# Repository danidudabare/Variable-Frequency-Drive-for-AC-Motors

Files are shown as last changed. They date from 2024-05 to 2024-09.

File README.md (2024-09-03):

# Variable Frequency Drive (VFD) for AC Motors

## Introduction
This project involves the design and development of a Variable Frequency Drive (VFD) for controlling the speed and torque of AC motors. The VFD adjusts the motor's input frequency and voltage, enabling precise control over motor performance in various industrial and commercial applications. This project is part of the EN2160 - Electronic Design Realization module at the University of Moratuwa.
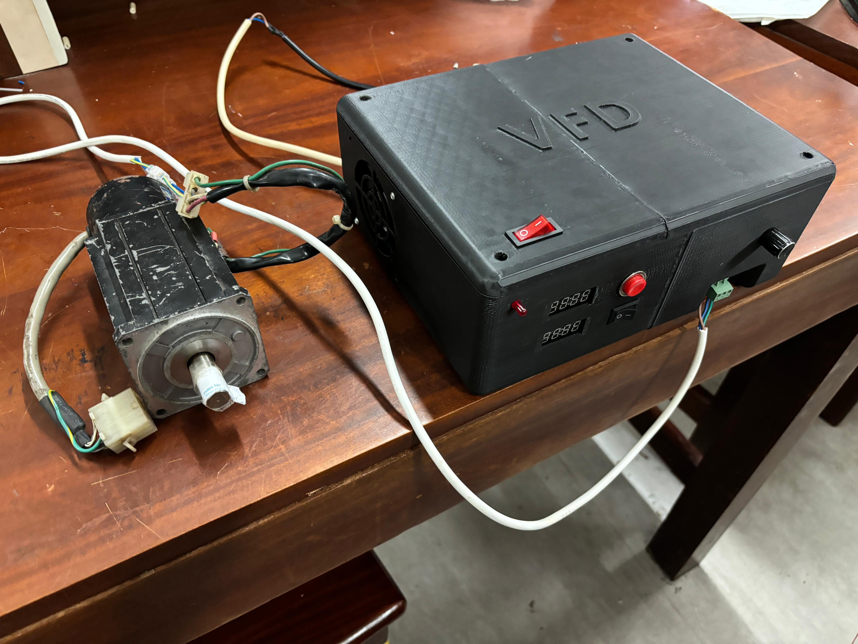
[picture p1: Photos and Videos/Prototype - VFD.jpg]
Prototype VFD


## Electronic Design
### Power Circuit
The Power Circuit is responsible for converting the high-voltage AC input to a stable DC output, which powers the motor and other components. Key elements include a full-wave rectifier, smoothing capacitors, and AC-DC converters. The design also incorporates a bypass relay circuit to manage inrush currents.

### Intelligent Power Module (IPM)
The IPM is the heart of the VFD, combining high-speed switching IGBTs with integrated protection features like overcurrent and thermal shutdown. It interfaces with the microcontroller unit (MCU) to receive control signals and provide system feedback.

### Microcontroller Unit (MCU)
The MCU controls the VFD operation by generating PWM signals that modulate the output frequency and voltage to the motor. It also manages system diagnostics, user input, and communication with the IPM. The MCU used in this project is the ATmega328-PU.

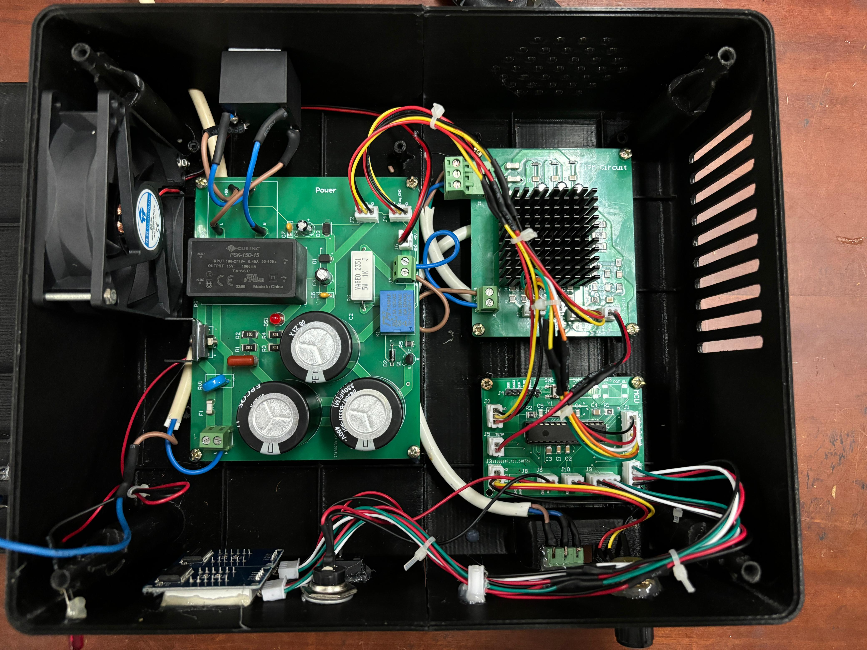
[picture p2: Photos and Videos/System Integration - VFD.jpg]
System Integration - VFD


## Enclosure Design
The enclosure for the VFD is designed to house all the electronic components securely, providing protection against environmental factors and physical damage. The enclosure is made of ABS material, designed with both top and bottom parts that are molded to fit the internal circuits. Detailed design drawings and 3D-printed prototypes were developed to ensure proper fit and functionality.

## Source Code
The source code for this project is written in C++ and is responsible for controlling the MCU. The code handles PWM generation, user inputs via potentiometers and switches, and displays motor parameters on digital LED displays. The code is optimized for real-time motor control, ensuring accurate and responsive operation of the VFD.

## Testing and Prototyping
Extensive testing and prototyping were conducted to ensure the reliability and performance of the VFD. This included PCB testing for power circuits, IPM, and MCU integration, as well as real-time testing with an AC motor to verify speed and torque control. The final prototype demonstrated successful operation under various load conditions, confirming the design's effectiveness.
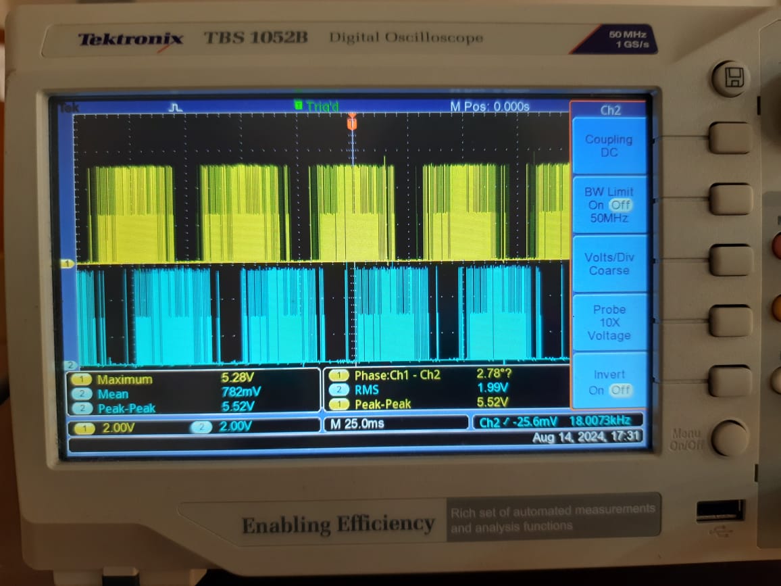
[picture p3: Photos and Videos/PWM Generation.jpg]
PWM Generation

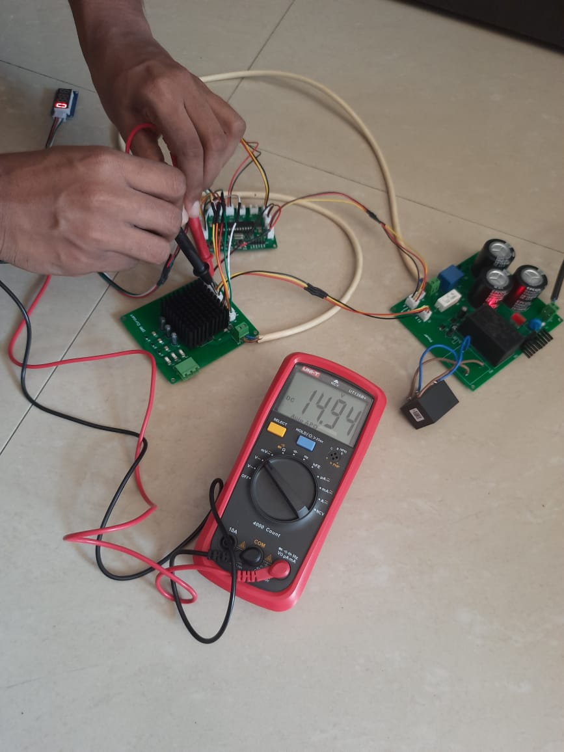
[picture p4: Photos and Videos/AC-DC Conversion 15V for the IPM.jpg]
AC-DC Conversion 15V for the IPM


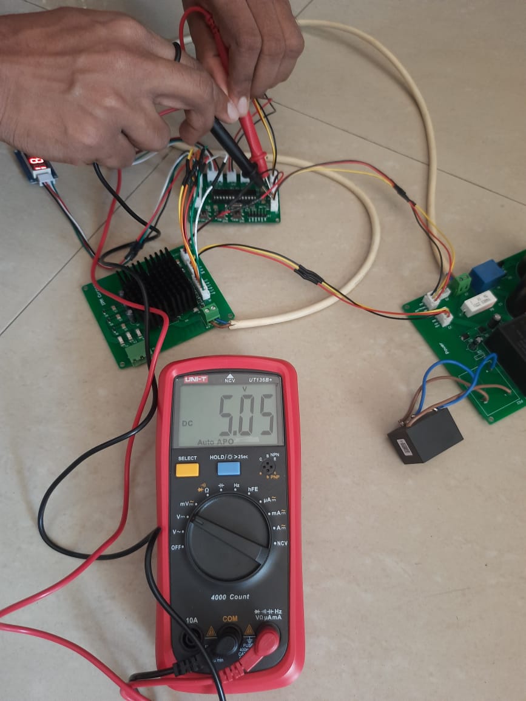
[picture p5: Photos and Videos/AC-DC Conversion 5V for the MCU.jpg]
AC-DC Conversion 5V for the MCU


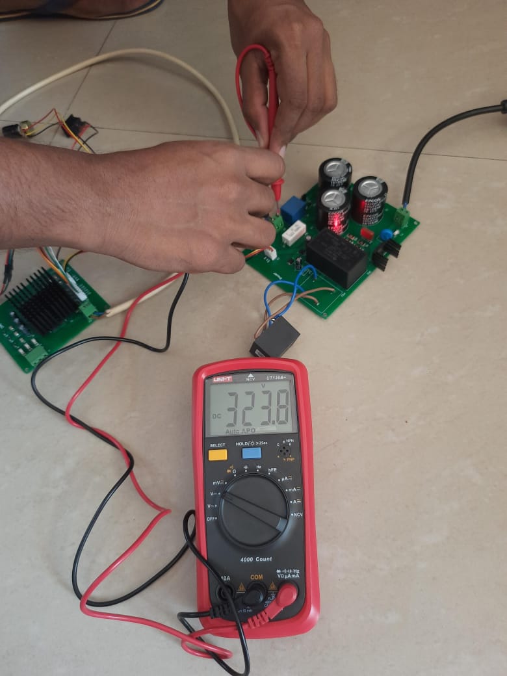
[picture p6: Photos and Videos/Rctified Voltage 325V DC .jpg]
Rectified Voltage 325V DC


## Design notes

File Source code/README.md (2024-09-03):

This project is designed for the ATmega328P (8-bit) microcontroller and is built without relying on Arduino libraries. It uses the AVR GCC 8-bit compiler and the standard C++ libraries. The modified TM1637Display library included in this repository is essential for the display functionality.

# Microcontroller
ATmega328P (8-bit)

# Modifications
Converted from Arduino to AVR: The code has been fully adapted to work with AVR libraries, removing dependencies on Arduino libraries.
Removed Unnecessary Functions: Functions related to single-phase AC motors have been removed as the project focuses solely on 3-phase AC motor control.
Added Reverse_3_Phase() Function: This new function allows reversing the rotation direction of the 3-phase AC motor.
Converted Display Libraries: The display functionality has been converted from Arduino-specific libraries to AVR-compatible libraries.

# Instructions for Compilation
To compile this code using the AVR GCC 8-bit compiler, follow these steps:

# 1. Include the Modified Display Library
Ensure you have included the modified TM1637Display library provided in this repository. This library is crucial for the correct operation of the displays used in this project.

# 2. Setting Up the Environment
Verify that the AVR GCC 8-bit compiler is correctly installed on your system.

# 3. Compiling the Code
Use your preferred IDE or command-line tools compatible with AVR GCC to compile the code. Ensure the modified TM1637Display library is included in the compilation process.

# Important Notes
Arduino-Free: This project does not use Arduino libraries and relies solely on AVR libraries and standard C++ libraries.
Port Requirements: The display functionality is designed to work exclusively with Port B pins. The code will not function correctly if other ports are used.

# License
This project is licensed under the MIT License.

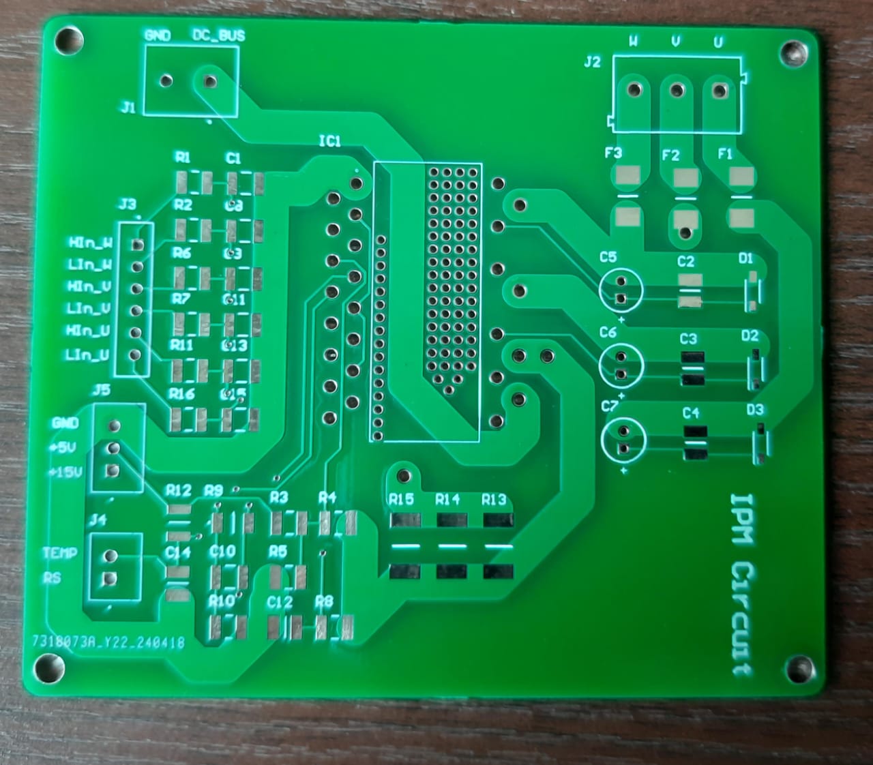
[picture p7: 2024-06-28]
Schematics and PCB Designs/2. IPM Circuit/IPM - Bare.jpg

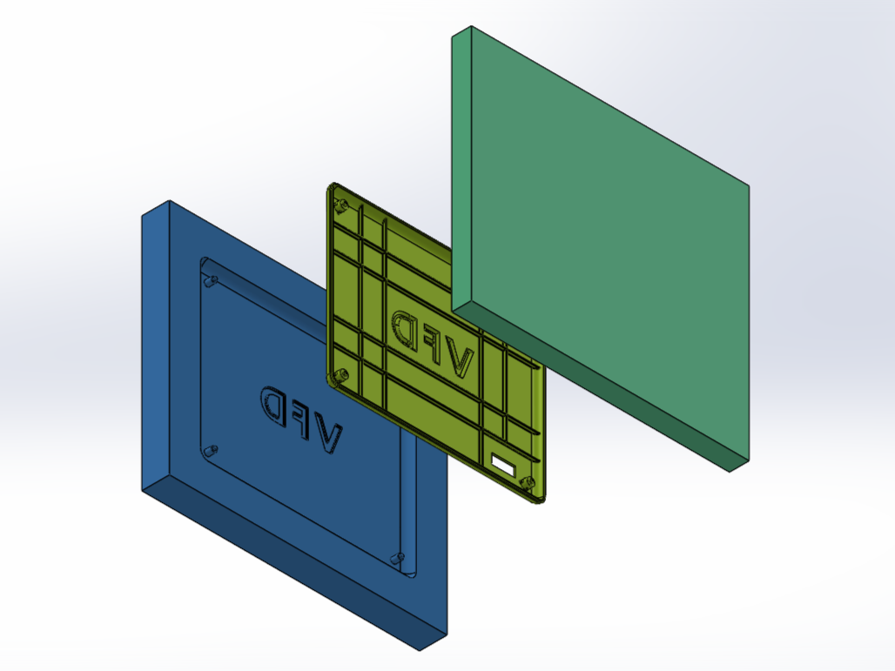
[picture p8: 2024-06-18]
Finalized Enclosure and Mold designs/Top cover mold design/Top part mold.png

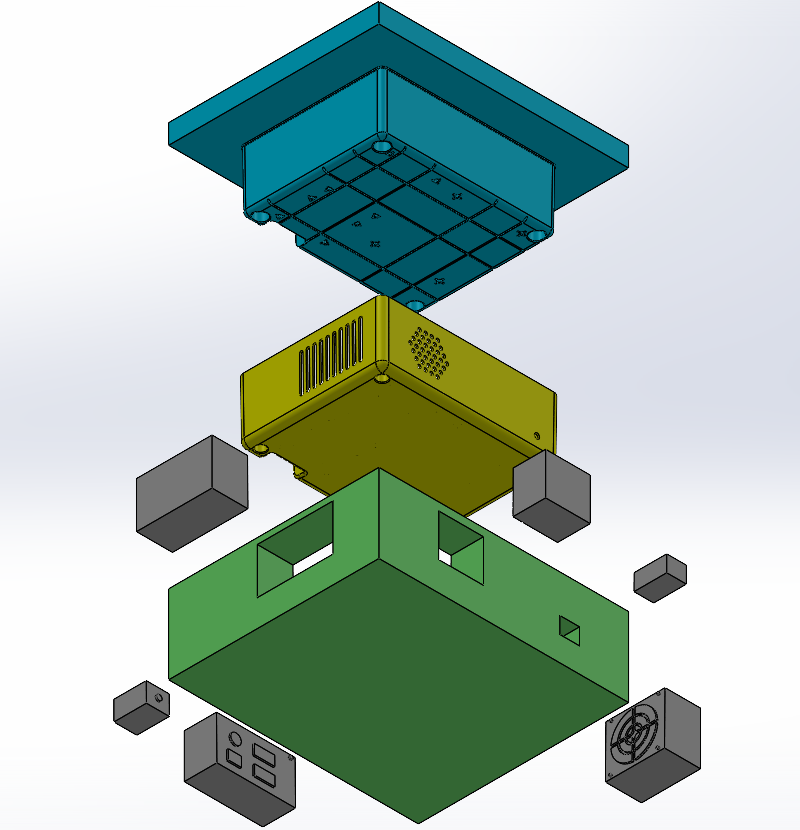
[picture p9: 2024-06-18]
Finalized Enclosure and Mold designs/Bottom part mold design/Bottom part mold exploded pov 2.png

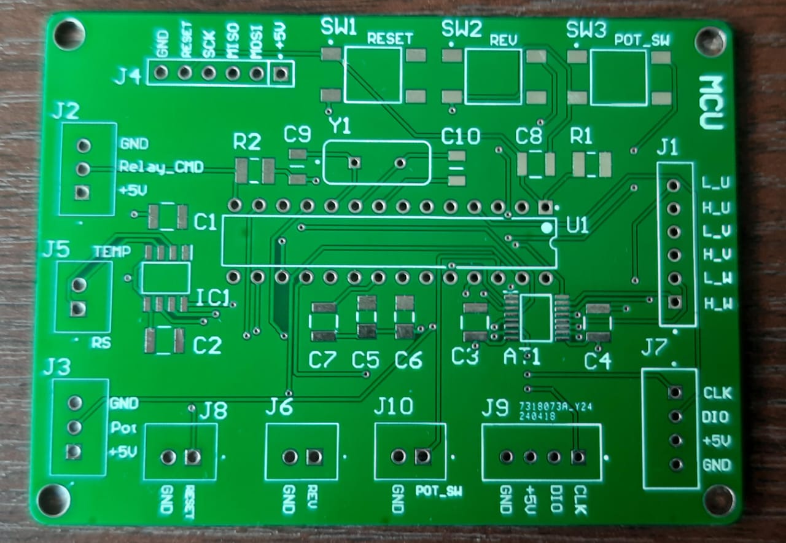
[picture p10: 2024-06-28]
Schematics and PCB Designs/3. MCU Circuit/MCU - Bare.jpg

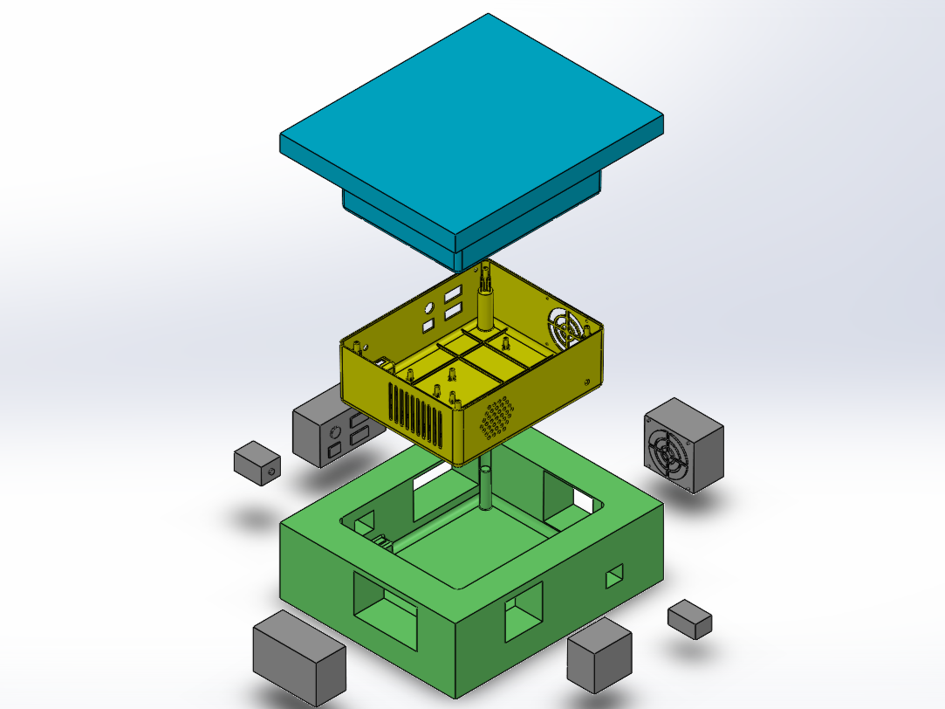
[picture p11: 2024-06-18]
Finalized Enclosure and Mold designs/Bottom part mold design/Bottom part mold exploded pov 1.png

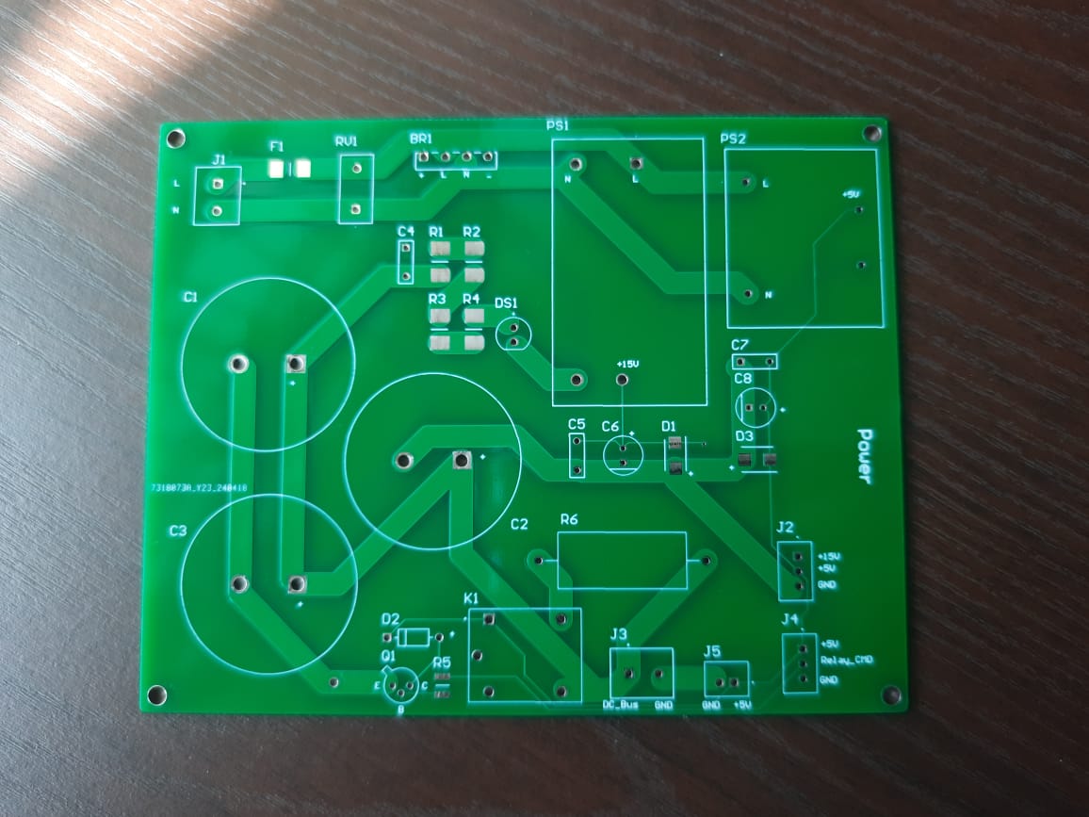
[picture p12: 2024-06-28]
Schematics and PCB Designs/1. Power Circuit/Power - Bare.jpg

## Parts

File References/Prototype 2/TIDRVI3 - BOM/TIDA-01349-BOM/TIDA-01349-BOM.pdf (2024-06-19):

TIDA-01349
Variant: | 001 | E1
Generated: 12/19/2017 12:08:40 PM
TID #: | 01349 | TIDA-01349 REV E1 Bill of Materials
Item # | Designator | Quantity | Value | PartNumber | Manufacturer | Description | PackageReference
1 | C1, C2, C3, C4, C7, C9, C10, C11, C14, C15, C17, C21, C22, C30, C32, C33, C34, C36, C38, C40, C41, C42, C46, C49, C53, C55, C56 | 27 | 0.1uF | C0603C104K5RACTU | Kemet | CAP, CERM, 0.1 uF, 50 V, +/- 10%, X7R, 0603 | 0603
2 | C5, C12 | 2 | 0.1uF | C1206C104K5RACTU | Kemet | CAP, CERM, 0.1 uF, 50 V, +/- 10%, X7R, 1206 | 1206
3 | C6, C13, C18, C19, C50, C51 | 6 | 4.7uF | C2012X7R1E475K125AB | TDK | CAP, CERM, 4.7 uF, 25 V, +/- 10%, X7R, 0805 | 0805
4 | C8, C16, C52 | 3 | 4700pF | C0603C472K5RACTU | Kemet | CAP, CERM, 4700 pF, 50 V, +/- 10%, X7R, 0603 | 0603
5 | C23, C24, C25, C27, C28, C29 | 6 | 1000pF | C0603C102J5GACTU | Kemet | CAP, CERM, 1000 pF, 50 V, +/- 5%, C0G/NP0, 0603 | 0603
6 | C26 | 1 | 2uF | B32774D0205K000 | TDK | CAP, Film, 2 uF, 1100 V, +/- 10%, 0.011 ohm, TH | 31.5x21.5x12.5mm
7 | C31, C35, C37, C39 | 4 | 2.2uF | UMK316B7225KL-T | Taiyo Yuden | CAP, CERM, 2.2 uF, 50 V, +/- 10%, X7R, 1206 | 1206
8 | C43 | 1 | 0.022uF | C0603C223K5RACTU | Kemet | CAP, CERM, 0.022 uF, 50 V, +/- 10%, X7R, 0603 | 0603
9 | C44 | 1 | 180pF | C0603C181J5GACTU | Kemet | CAP, CERM, 180 pF, 50 V, +/- 5%, C0G/NP0, 0603 | 0603
10 | C45 | 1 | 0.01uF | GRM188R71H103KA01D | MuRata | CAP, CERM, 0.01 uF, 50 V, +/- 10%, X7R, 0603 | 0603
11 | C47 | 1 | 10uF | C3225X7R1H106M250AC | TDK | CAP, CERM, 10 uF, 50 V, +/- 20%, X7R, 1210 | 1210
12 | D1, D2, D3, D4 | 4 | 20V | DFLZ20-7 | Diodes Inc. | Diode, Zener, 20 V, 1 W, PowerDI123 | PowerDI123
13 | J1 | 1 | | HSEC8-160-01-L-DV-A-BL | Samtec | C2000 controlCARD-120HSEC connector, SMT | C2000 pin numbering
14 | J2 | 1 | | 61301021121 | Wurth Elektronik | Header, 2.54 mm, 5x2, Gold, TH | Header, 2.54mm, 5x2, TH
15 | J3 | 1 | | HSEC8-130-01-L-DV-A | Samtec | C2000 controlCARD-180HSEC (60-pin addon) connector, SMT | C2000 pin numbering
16 | J4, J5, J6 | 3 | | 1902547 | Phoenix Contact | Terminal Block, 9.52mm, 2x1, R/A, TH | Terminal Block, 2x1, Pitch 9.52mm
17 | J7 | 1 | | PEC07DAAN | Sullins Connector Solutions | Header, 100mil, 7x2, Tin, TH | Header, 7x2, 100mil, Tin
18 | J8, J9 | 2 | | PEC01DAAN | Sullins Connector Solutions | Header, 2.54mm, 1x2, Tin, Black, TH | Header, 2.54mm, 2x1, TH
19 | Q1 | 1 | 20V | MGSF1N02LT1G | ON Semiconductor | MOSFET, N-CH, 20 V, 0.75 A, SOT-23 | SOT-23
20 | R1, R2, R3, R4, R5, R6, R7, R8, R9, R10, R38, R39, R46, R47 | 14 | 22.0 | RC0603FR-0722RL | Yageo America | RES, 22.0, 1%, 0.1 W, 0603 | 0603
21 | R11, R26 | 2 | 187 | CRCW0603187RFKEA | Vishay-Dale | RES, 187, 1%, 0.1 W, 0603 | 0603
22 | R12, R15, R17, R21, R23, R25, R29 | 7 | 100 | CRCW0603100RFKEA | Vishay-Dale | RES, 100, 1%, 0.1 W, 0603 | 0603
23 | R13, R14, R16, R20, R22, R24 | 6 | 100k | CRCW1206100KFKEA | Vishay-Dale | RES, 100 k, 1%, 0.25 W, 1206 | 1206
24 | R18, R19 | 2 | 0.005 | CSNL1206FT5L00 | Stackpole Electronics Inc | RES, 0.005, 1%, 1 W, 1206 | 1206

Item # | Designator | Quantity | Value | PartNumber | Manufacturer | Description | PackageReference
25 | R27, R28, R36, R43, R44, R45 | 6 | 10.0k | CRCW060310K0FKEA | Vishay-Dale | RES, 10.0 k, 1%, 0.1 W, 0603 | 0603
26 | R30, R32, R37, R40, R42 | 5 | 0 | CRCW06030000Z0EA | Vishay-Dale | RES, 0, 5%, 0.1 W, 0603 | 0603
27 | R31 | 1 | 4.42k | RC0603FR-074K42L | Yageo America | RES, 4.42 k, 1%, 0.1 W, 0603 | 0603
28 | R35 | 1 | 402 | CRCW0603402RFKEA | Vishay-Dale | RES, 402, 1%, 0.1 W, 0603 | 0603
29 | R41 | 1 | 32.4k | RC0603FR-0732K4L | Yageo America | RES, 32.4 k, 1%, 0.1 W, 0603 | 0603
30 | U1 | 1 | | ISO7760FDWR | Texas Instruments | High Speed, Robust EMC Six-Channel Digital Isolators, DW0016B (SOIC-16) | DW0016B
31 | U2, U4 | 2 | | TLV76050DBZR | Texas Instruments | 100-mA, 30-V, Fixed-Output, Linear-Voltage Regulator, DBZ0003A (SOT-23-3) | DBZ0003A
32 | U3, U5 | 2 | | AMC1303M0520DWVR | Texas Instruments | Small Reinforced Isolated Modulator With +/-50mV Input, Internal Clock, and CMOS Interface, DWV0008A (SOIC-8) | DWV0008A
33 | U6 | 1 | | TPS7A4201DGNR | Texas Instruments | Single Output LDO, 50 mA, Adjustable 1.175 to 26 V Output, 7 to 28 V Input, 8-pin MSOP (DGN), -40 to 125 degC, Green (RoHS & no Sb/Br) | DGN0008B
34 | U7, U8 | 2 | | AMC1303M2520DWVR | Texas Instruments | Small Reinforced Isolated Modulator With +/-250mV Input, Internal Clock, and CMOS Interface, DWV0008A (SOIC-8) | DWV0008A
35 | U9 | 1 | | PSS15SA2FT | Mitsubishi | Dual-In-Line Package Intelligent Power Module, TH | 79x31mm
36 | U10 | 1 | | TPS70633DBVR | Texas Instruments | 150-mA, 6.5-V, 1-uA IQ Voltage Regulators with Enable, DBV0005A (SOT-23-5) | DBV0005A
37 | FID1, FID2, FID3, FID4, FID5, FID6 | 0 | | N/A | N/A | Fiducial mark. There is nothing to buy or mount. | N/A

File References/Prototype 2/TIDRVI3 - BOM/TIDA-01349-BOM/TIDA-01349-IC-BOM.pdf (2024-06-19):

TIDA-01349
Variant: | 001 | E1
Generated: 12/19/2017 1:41:23 PM
TID #: | 01349 | TIDA-01349 REV E1 Bill of Materials
Item # | Designator | Quantity | Value | PartNumber | Manufacturer | Description | PackageReference
1 | C1, C2, C3, C4 | 4 | 0.1uF | C0603C104K5RACTU | Kemet | CAP, CERM, 0.1 uF, 50 V, +/- 10%, X7R, 0603 | 0603
2 | J1 | 1 | | PPTC072LJBN-RC | Sullins Connector Solutions | Receptacle, 2.54mm, 7x2, Tin, Black, R/A, TH | Receptacle, 2.54mm, 7x2, R/A, TH
3 | R1, R2, R3, R4, R5, R6 | 6 | 10.0k | CRCW040210K0FKED | Vishay-Dale | RES, 10.0 k, 1%, 0.063 W, 0402 | 0402
4 | U1 | 1 | | SN74LVC86A | Texas Instruments | Quadruple 2-Input Exclusive-OR Gate, PW0014A, TUBE | PW0014A
5 | U2, U3 | 2 | | SN74LVC08A | Texas Instruments | Quadruple 2-Input Positive-AND Gate, PW0014A, TUBE | PW0014A

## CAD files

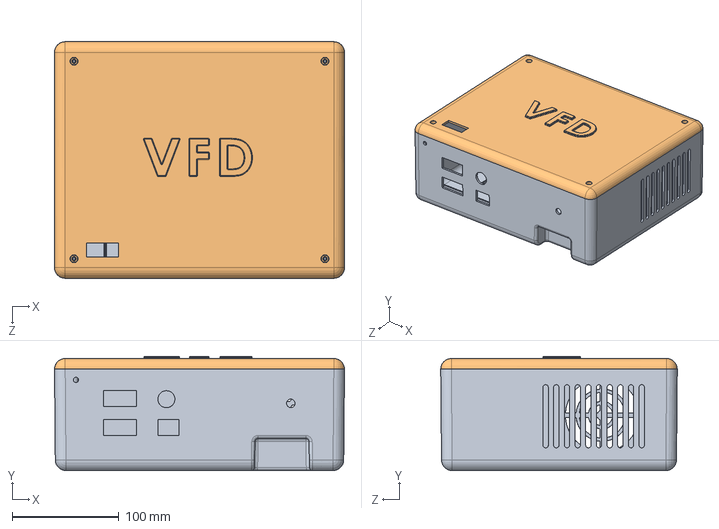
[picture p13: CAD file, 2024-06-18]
Finalized Enclosure and Mold designs/Assembly VFD.SLDASM
271.7 x 107.0 x 221.7 mm
Main
Top cover VFD

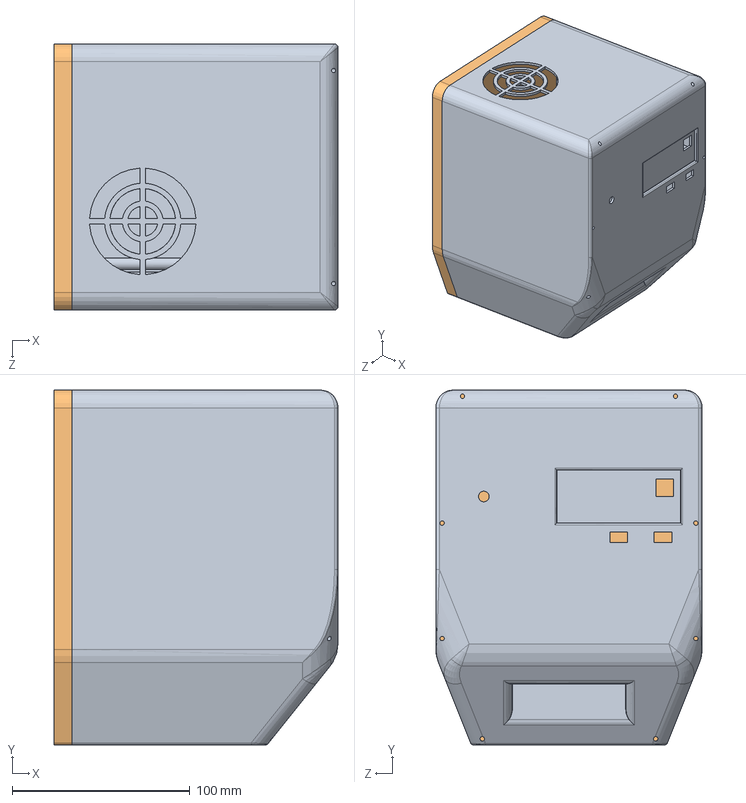
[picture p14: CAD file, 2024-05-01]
Enclosure first attempt/Assem1.SLDASM
160.0 x 200.0 x 150.0 mm
EDR part 1
Back lid

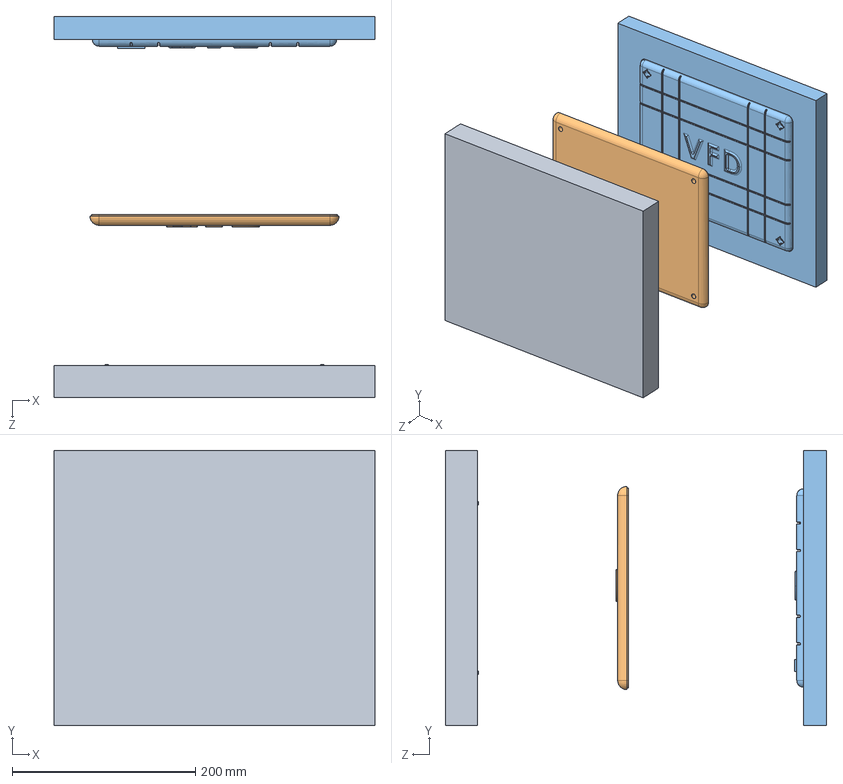
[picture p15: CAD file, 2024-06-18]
Finalized Enclosure and Mold designs/Top cover mold design/Top cover mold assembly.SLDASM
350.0 x 300.0 x 415.5 mm
Tooling Split1[1]_Top cover
Parting Line1_Top cover
Tooling Split1[2]_Top cover

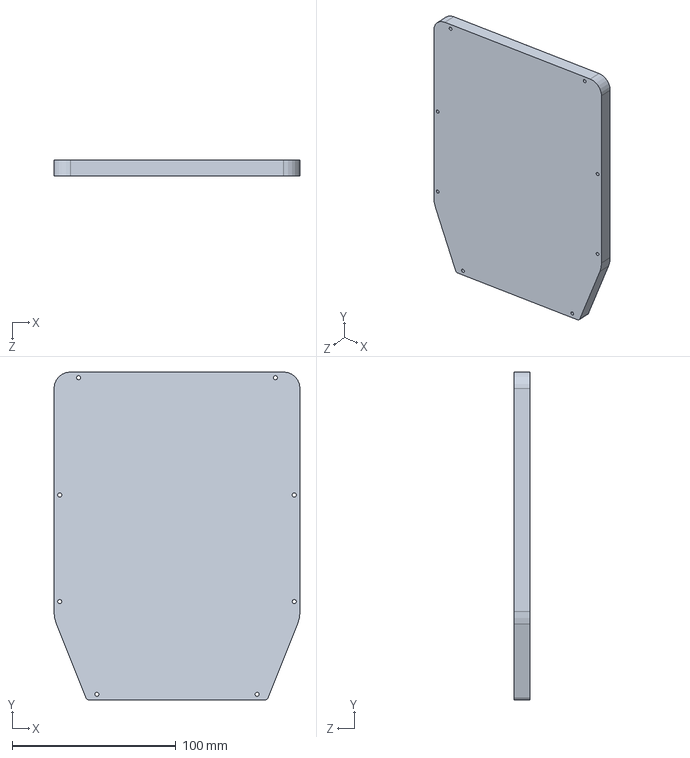
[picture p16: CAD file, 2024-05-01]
Enclosure first attempt/Back lid.SLDPRT
150.0 x 200.0 x 10.0 mm

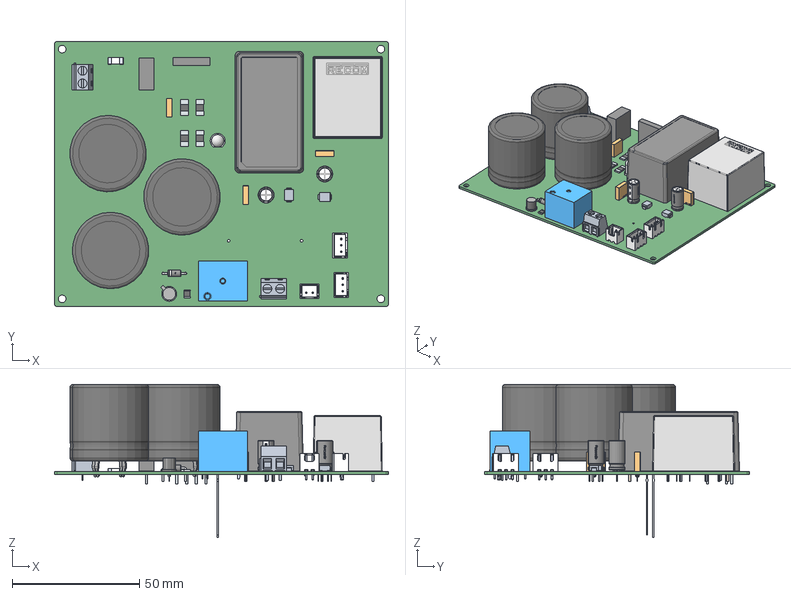
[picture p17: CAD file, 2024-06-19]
Schematics and PCB Designs/1. Power Circuit/Power Circuit.step
131.0 x 104.0 x 60.0 mm
BxB-XH-A_02
c-282836-2-h-3d x 2
terminal x 5
logo x 5
Leads x 2
STEP-WL-TMRC-5mm-wos-rev1
term1 x 5
term2 x 5
Extruded x 2
Diotec Logo
marking x 2
bottom x 2
polarity marking x 2
top x 2

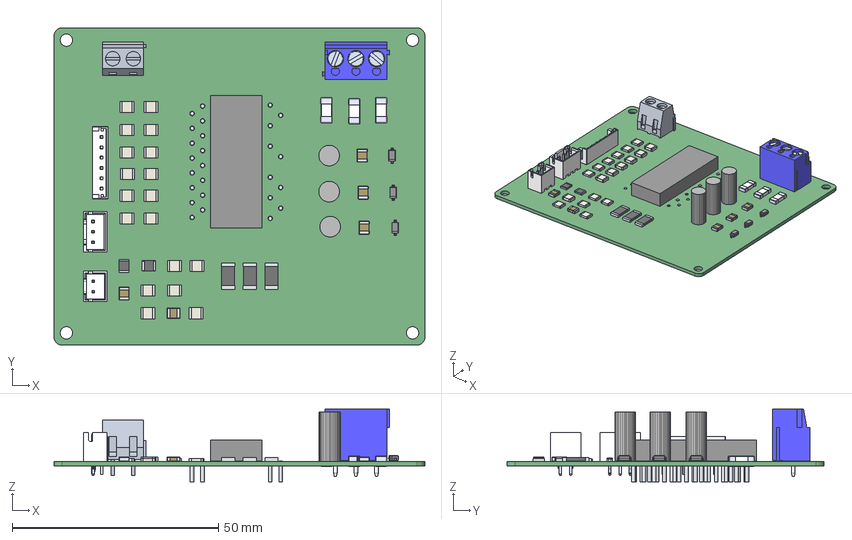
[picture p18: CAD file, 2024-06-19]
Schematics and PCB Designs/2. IPM Circuit/IPM Circuit.step
90.0 x 77.0 x 17.6 mm
BxB-XH-A_02
Extruded x 57
term1 x 4
term2 x 4
solidBody
Terminal
solidTop
Notch
JST
Insulator
Wire guard x 3
Screw x 3
Pin x 3
c-282836-2-h-3d
Leads x 26

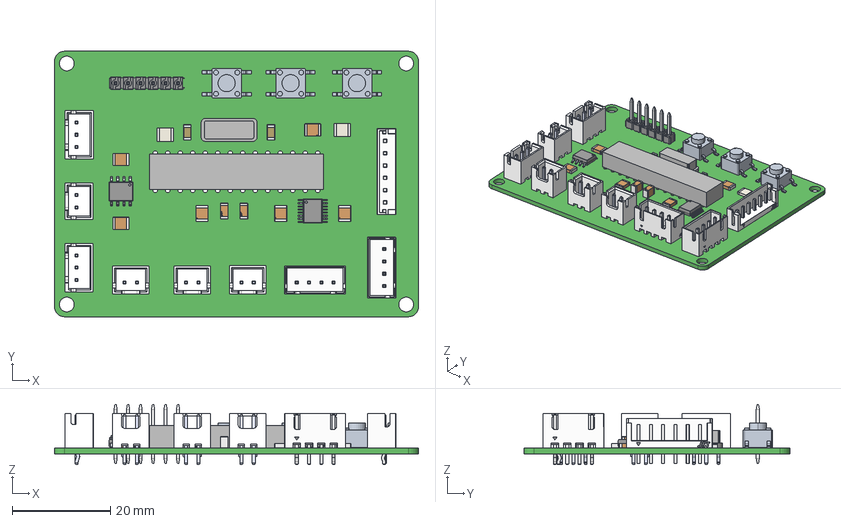
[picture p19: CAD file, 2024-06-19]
Schematics and PCB Designs/3. MCU Circuit/MCU Circuit.step
74.0 x 54.0 x 12.3 mm
c-4-1437565-2-s-3d x 3
Extruded x 9
Pin1_Triangle x 2
JST x 3
Molex Logo
BxB-XH-A_02 x 4
PinsArrayLR x 2
AVX Logo 2 x 6
AVX_Logo x 2
Notch

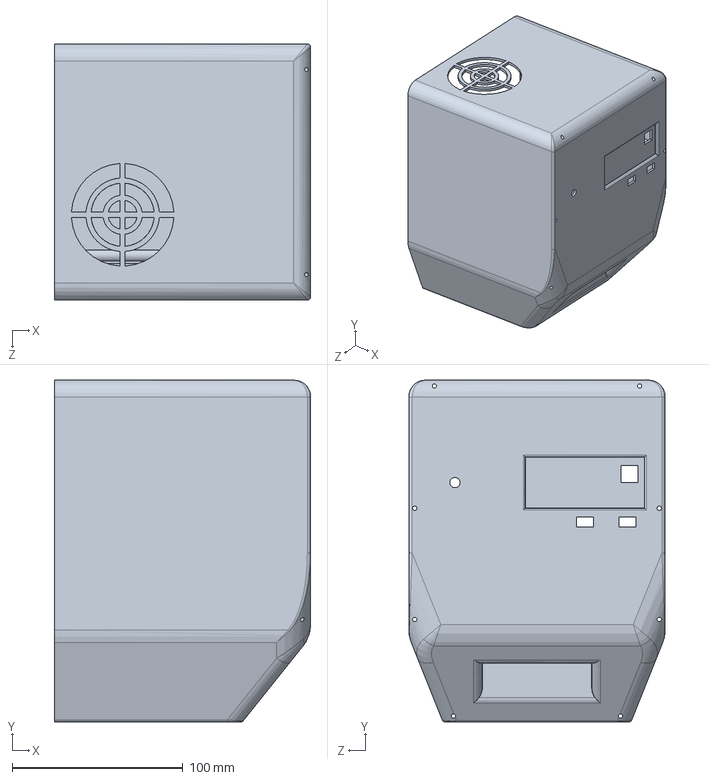
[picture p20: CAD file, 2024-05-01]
Enclosure first attempt/EDR part 1.SLDPRT
150.0 x 200.0 x 150.0 mm

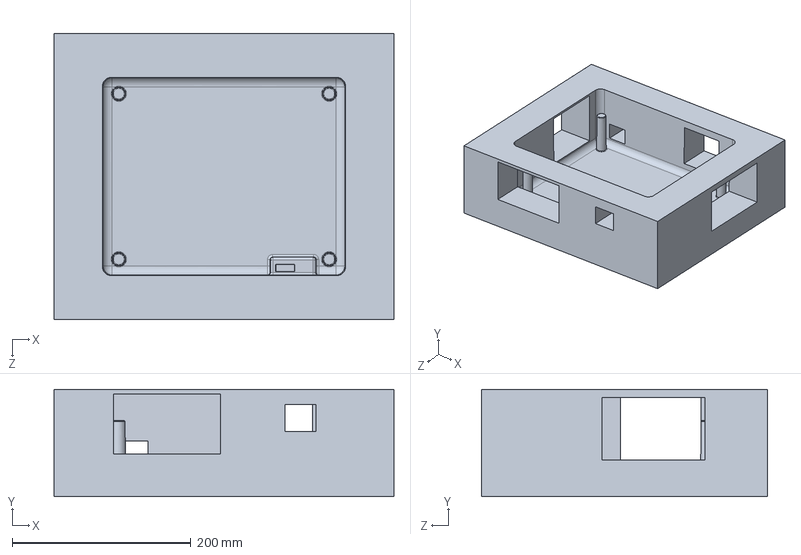
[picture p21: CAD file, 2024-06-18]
Finalized Enclosure and Mold designs/Bottom part mold design/Body2.SLDPRT
380.0 x 120.0 x 320.0 mm

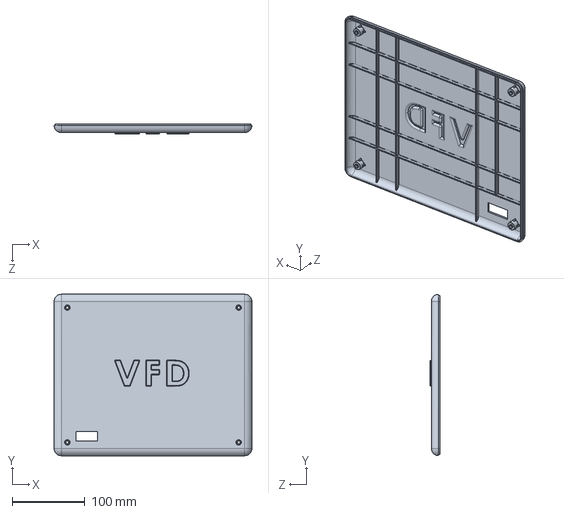
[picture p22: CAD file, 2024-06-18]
Finalized Enclosure and Mold designs/Top cover VFD.SLDPRT
271.7 x 221.7 x 14.0 mm

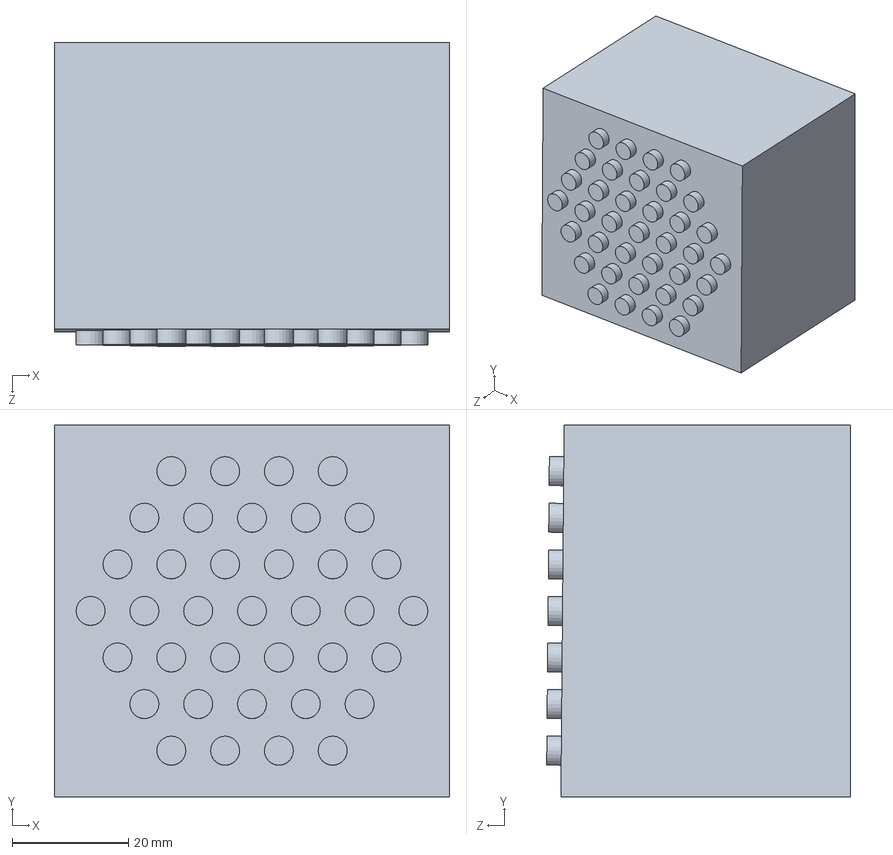
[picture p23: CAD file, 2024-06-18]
Finalized Enclosure and Mold designs/Bottom part mold design/Body1.SLDPRT
68.0 x 64.0 x 52.3 mm

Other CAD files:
Finalized Enclosure and Mold designs/Bottom part mold design/Body9.SLDPRT
Finalized Enclosure and Mold designs/Top cover mold design/Parting Line1_Top cover.SLDPRT
Finalized Enclosure and Mold designs/Top cover mold design/Tooling Split1[2]_Top cover.SLDPRT
Finalized Enclosure and Mold designs/Bottom part mold design/Body4.SLDPRT
Finalized Enclosure and Mold designs/Top cover mold design/Tooling Split1[1]_Top cover.SLDPRT
Finalized Enclosure and Mold designs/Bottom part mold design/Parting Line1.SLDPRT
Finalized Enclosure and Mold designs/Bottom part mold design/Body6.SLDPRT
Finalized Enclosure and Mold designs/Bottom part mold design/Body3.SLDPRT
Finalized Enclosure and Mold designs/Bottom part mold design/Body7.SLDPRT
Finalized Enclosure and Mold designs/Bottom part mold design/Tooling Split10[2].SLDPRT

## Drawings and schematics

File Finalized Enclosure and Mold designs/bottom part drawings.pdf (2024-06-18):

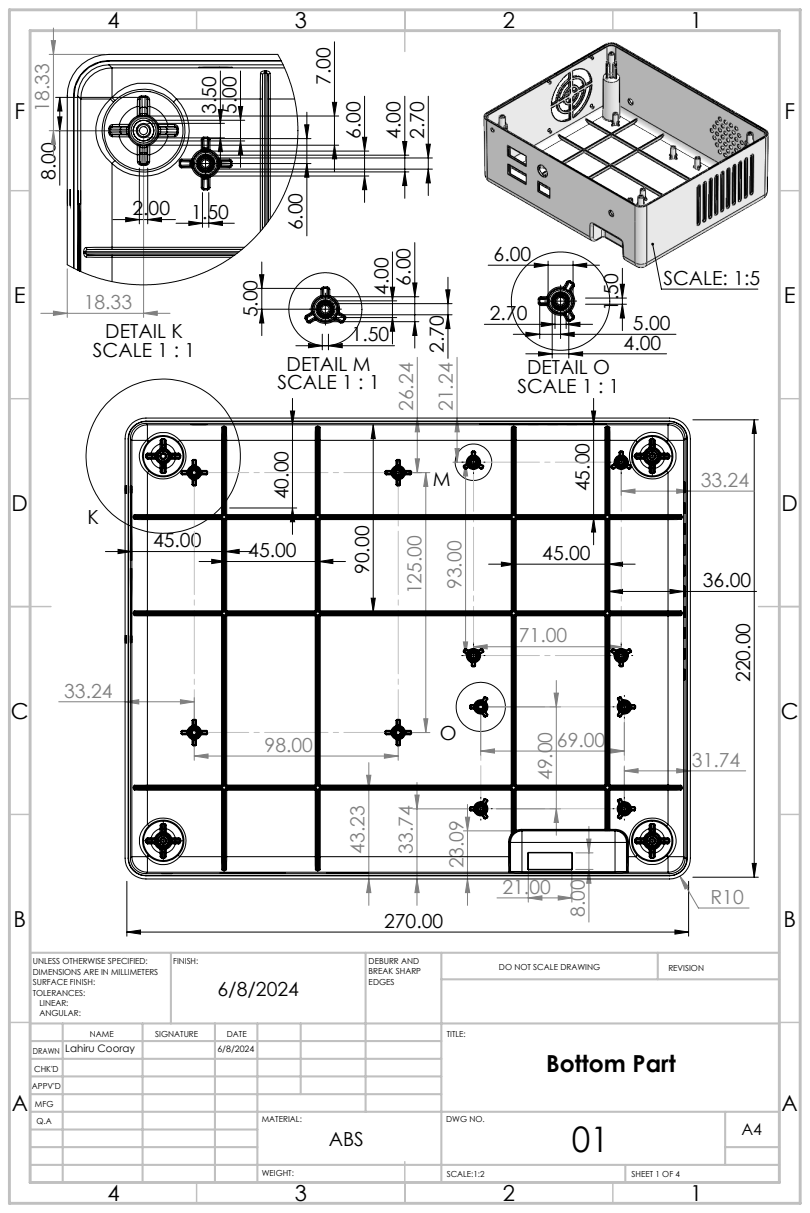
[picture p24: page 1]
SCALE: 1:5 220.00; DETAIL K SCALE 1 : 1; DETAIL M SCALE 1 : 1; DETAIL O SCALE 1 : 1; FINISH:; DEBURR AND; BREAK SHARP; DO NOT SCALE DRAWING; REVISION; SCALE:1:2; SHEET 1 OF 4

UNLESS OTHERWISE SPECIFIED:
DIMENSIONS ARE IN MILLIMETERS
SURFACE FINISH:
TOLERANCES:
LINEAR:
ANGULAR:

NAME | SIGNATURE | DATE | | | | TITLE: Bottom Part

DRAWN | Lahiru Cooray | | 6/8/2024

CHK'D
APPV'D
MFG
Q.A | | | | MATERIAL: ABS | DWG NO. 01 | A4

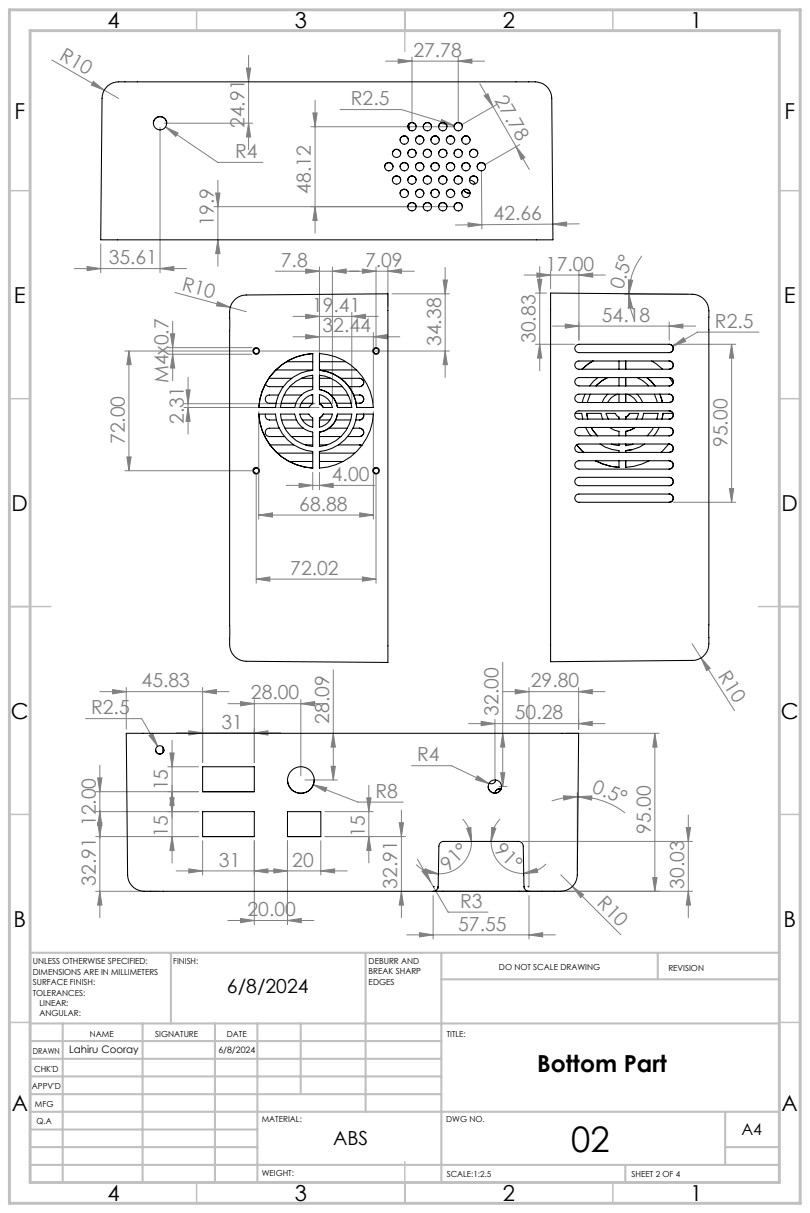
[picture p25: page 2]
FINISH:; DEBURR AND; BREAK SHARP; DO NOT SCALE DRAWING; REVISION

UNLESS OTHERWISE SPECIFIED:
DIMENSIONS ARE IN MILLIMETERS
SURFACE FINISH:
TOLERANCES:
LINEAR:
ANGULAR:

NAME | SIGNATURE | DATE | | | TITLE:

DRAWN | | | 6/8/2024 | | | Bottom Part Lahiru Cooray
CHK'D
APPV'D
MFG

ABS

SCALE:1:2.5 | SHEET 2 OF 4

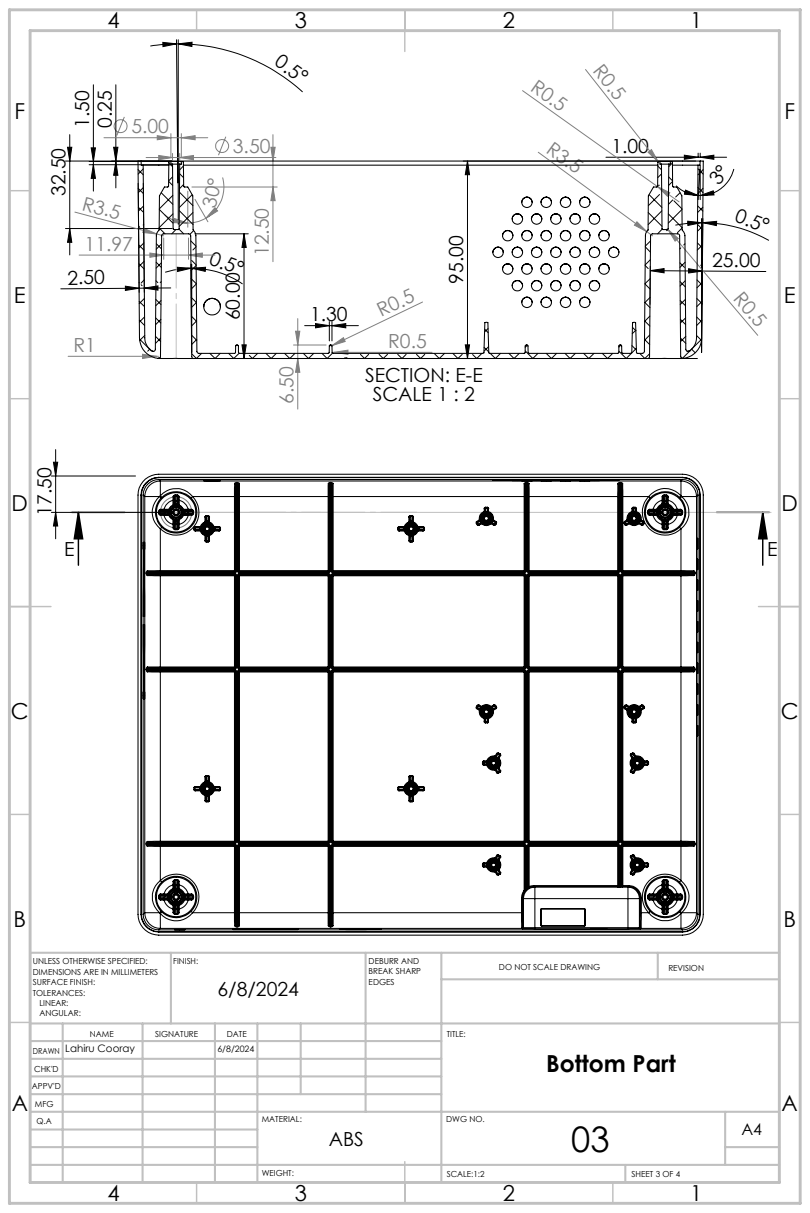
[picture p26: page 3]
SECTION: E-E SCALE 1 : 2; FINISH:; DEBURR AND; BREAK SHARP; DO NOT SCALE DRAWING; REVISION

UNLESS OTHERWISE SPECIFIED:
DIMENSIONS ARE IN MILLIMETERS
SURFACE FINISH:
TOLERANCES:
LINEAR:
ANGULAR:

NAME | SIGNATURE | DATE | TITLE: Bottom Part

DRAWN | Lahiru Cooray | | 6/8/2024

CHK'D
APPV'D
MFG

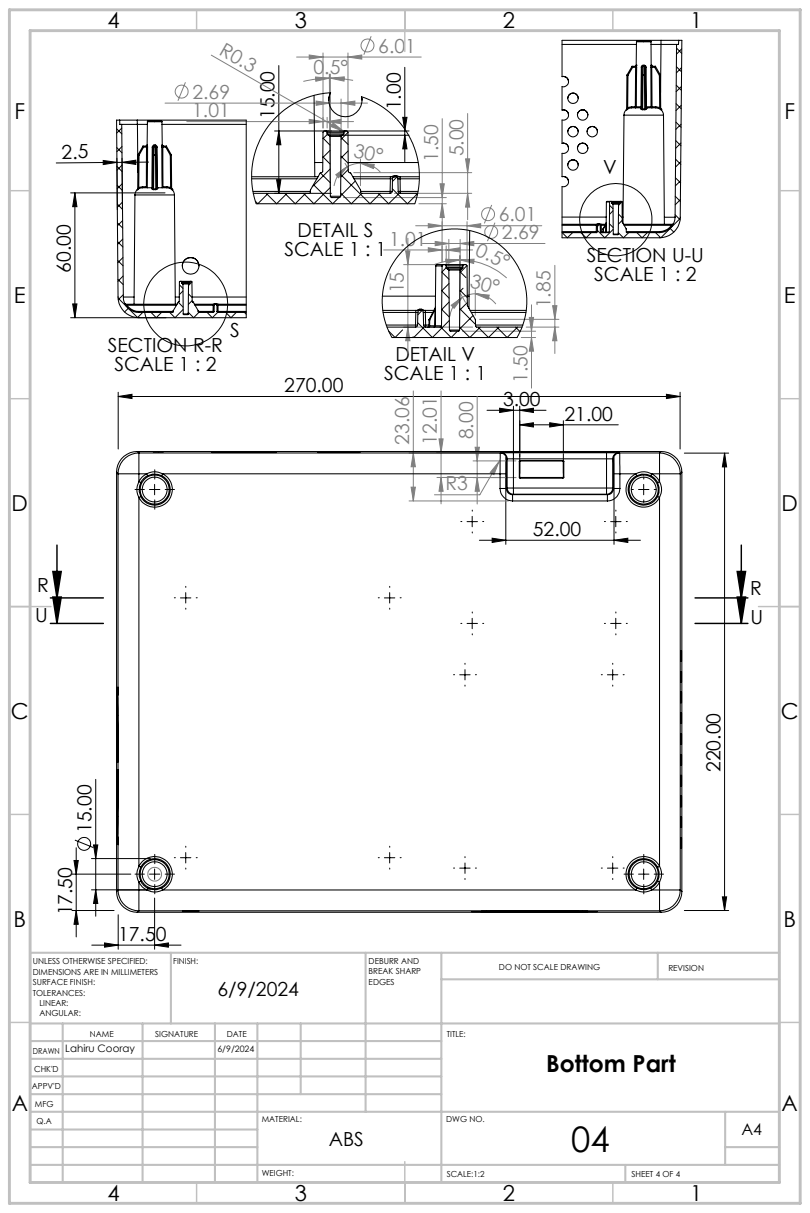
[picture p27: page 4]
S SECTION R-R SCALE 1 : 2; DETAIL S SCALE 1 : 1; SECTION U-U SCALE 1 : 2; DETAIL V SCALE 1 : 1; FINISH:; DEBURR AND; BREAK SHARP; DO NOT SCALE DRAWING; REVISION

UNLESS OTHERWISE SPECIFIED:
DIMENSIONS ARE IN MILLIMETERS
SURFACE FINISH:
TOLERANCES:
LINEAR:
ANGULAR:

NAME | SIGNATURE | DATE | TITLE: Bottom Part

DRAWN | Lahiru Cooray | | 6/9/2024

CHK'D
APPV'D
MFG

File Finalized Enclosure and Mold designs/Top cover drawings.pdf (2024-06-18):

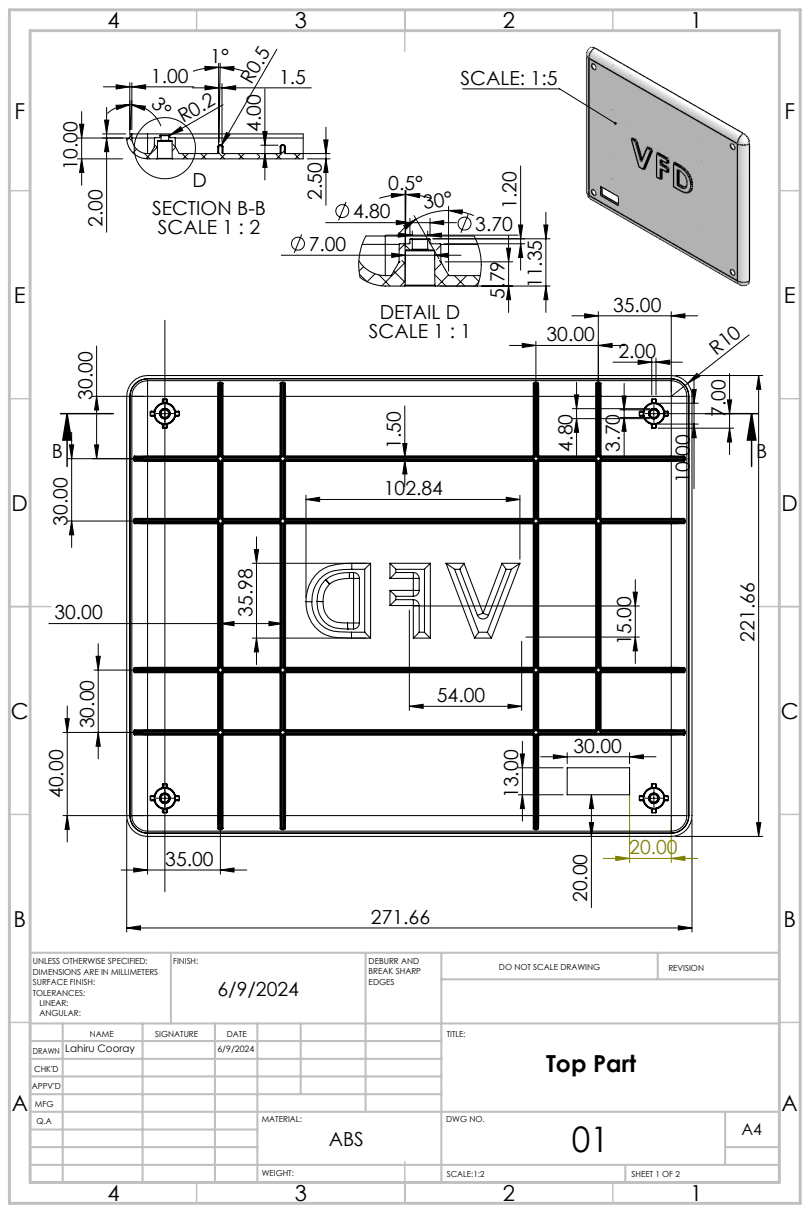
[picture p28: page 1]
SCALE: 1:5; SECTION B-B SCALE 1 : 2; DETAIL D SCALE 1 : 1; FINISH:; DEBURR AND; BREAK SHARP; DO NOT SCALE DRAWING; REVISION; SCALE:1:2; SHEET 1 OF 2

UNLESS OTHERWISE SPECIFIED:
DIMENSIONS ARE IN MILLIMETERS
SURFACE FINISH:
TOLERANCES:
LINEAR:
ANGULAR:

NAME | SIGNATURE | DATE | | | | TITLE: Top Part

DRAWN | Lahiru Cooray | | 6/9/2024

CHK'D
APPV'D
MFG
Q.A | | | | MATERIAL: ABS | DWG NO. 01 | A4

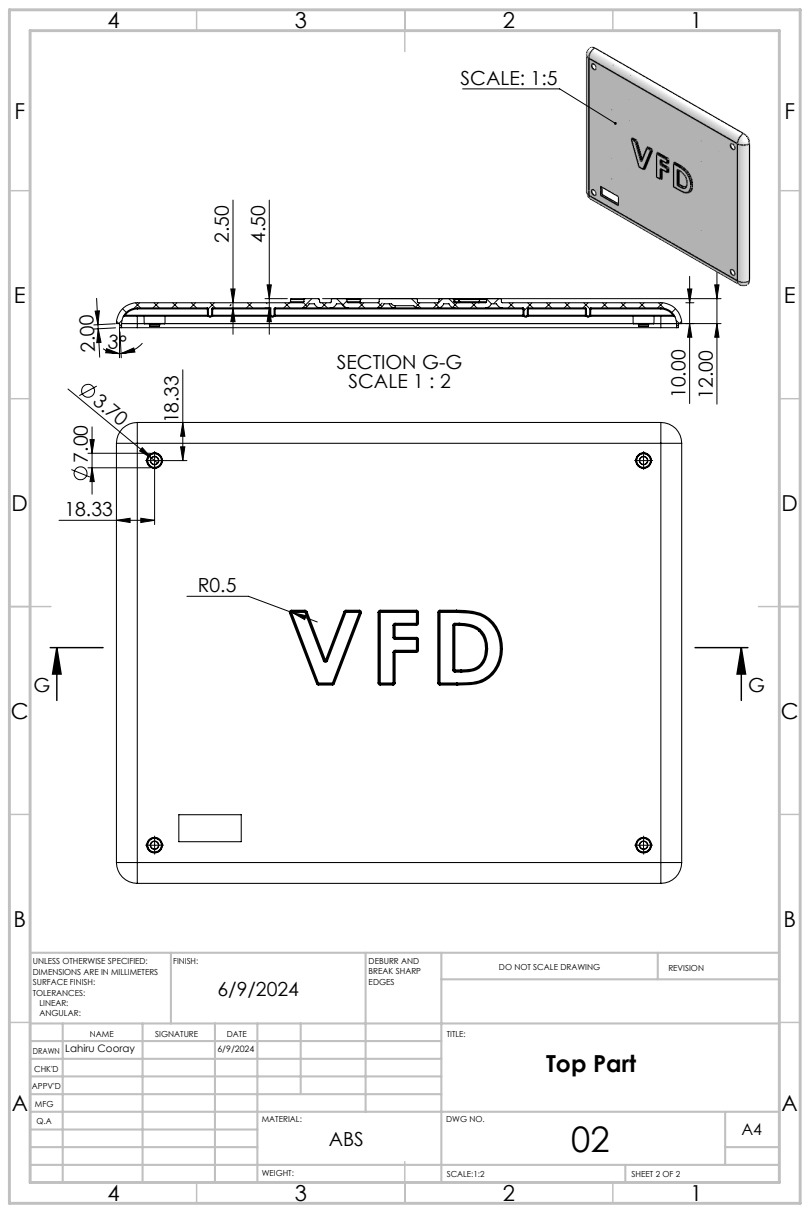
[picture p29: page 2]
SCALE: 1:5; SECTION G-G SCALE 1 : 2; FINISH:; DEBURR AND; BREAK SHARP; DO NOT SCALE DRAWING; REVISION; SCALE:1:2; SHEET 2 OF 2

UNLESS OTHERWISE SPECIFIED:
DIMENSIONS ARE IN MILLIMETERS
SURFACE FINISH:
TOLERANCES:
LINEAR:
ANGULAR:

NAME | SIGNATURE | DATE | | | | TITLE: Top Part

DRAWN | Lahiru Cooray | | 6/9/2024

CHK'D
APPV'D
MFG
Q.A | | | | MATERIAL: ABS | DWG NO. 02 | A4

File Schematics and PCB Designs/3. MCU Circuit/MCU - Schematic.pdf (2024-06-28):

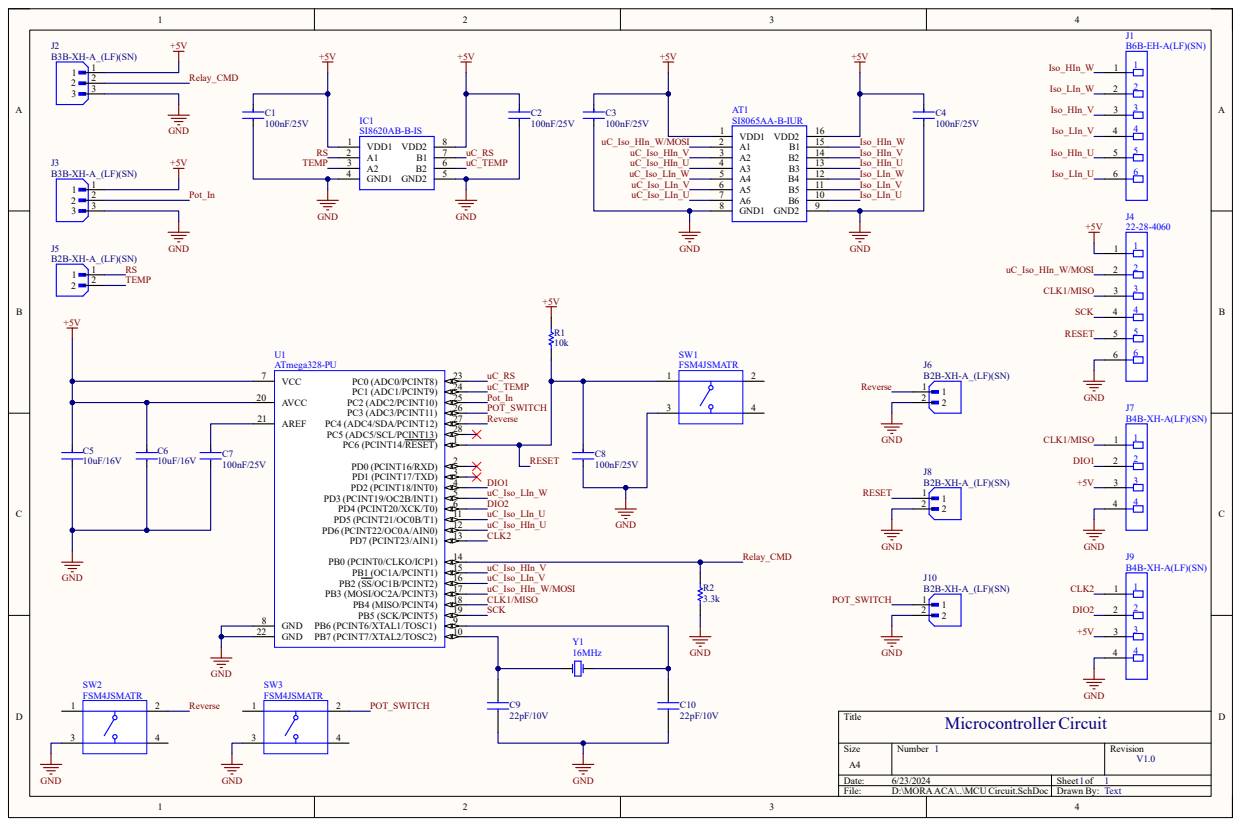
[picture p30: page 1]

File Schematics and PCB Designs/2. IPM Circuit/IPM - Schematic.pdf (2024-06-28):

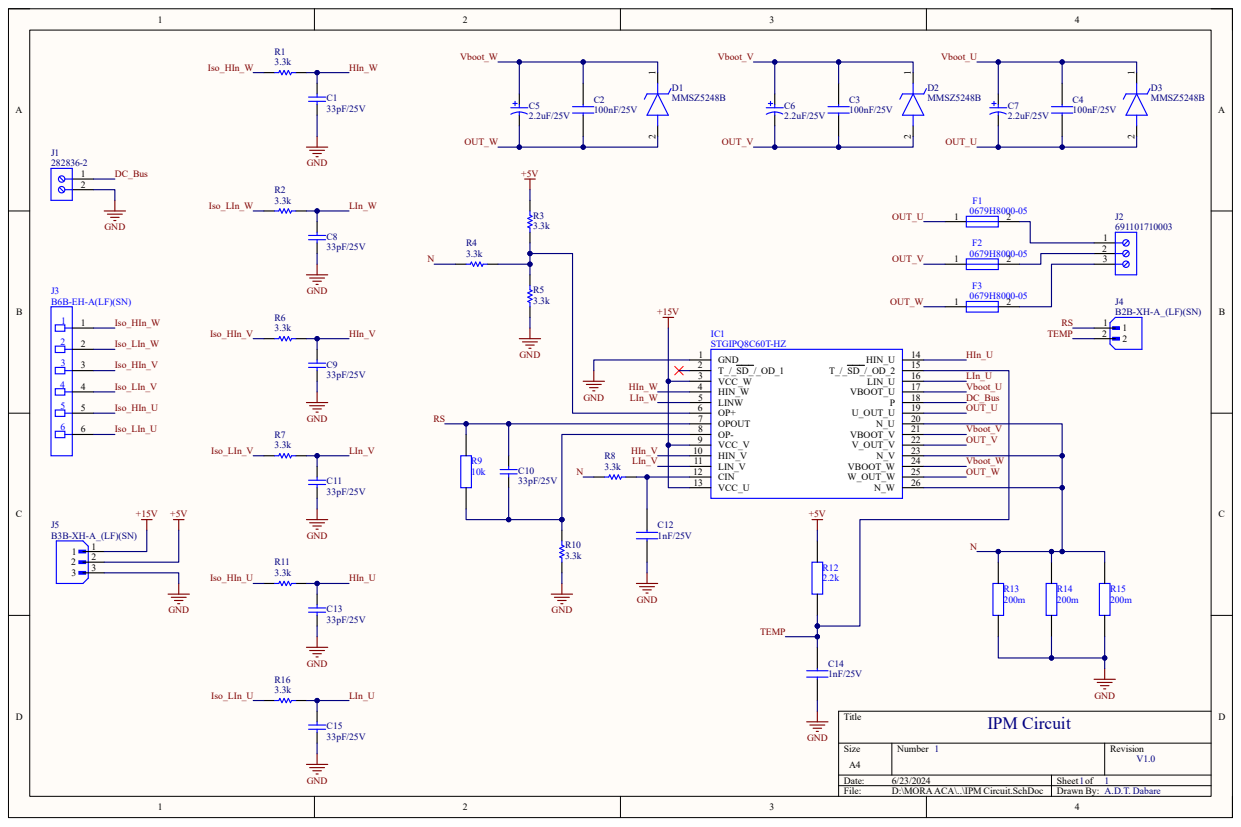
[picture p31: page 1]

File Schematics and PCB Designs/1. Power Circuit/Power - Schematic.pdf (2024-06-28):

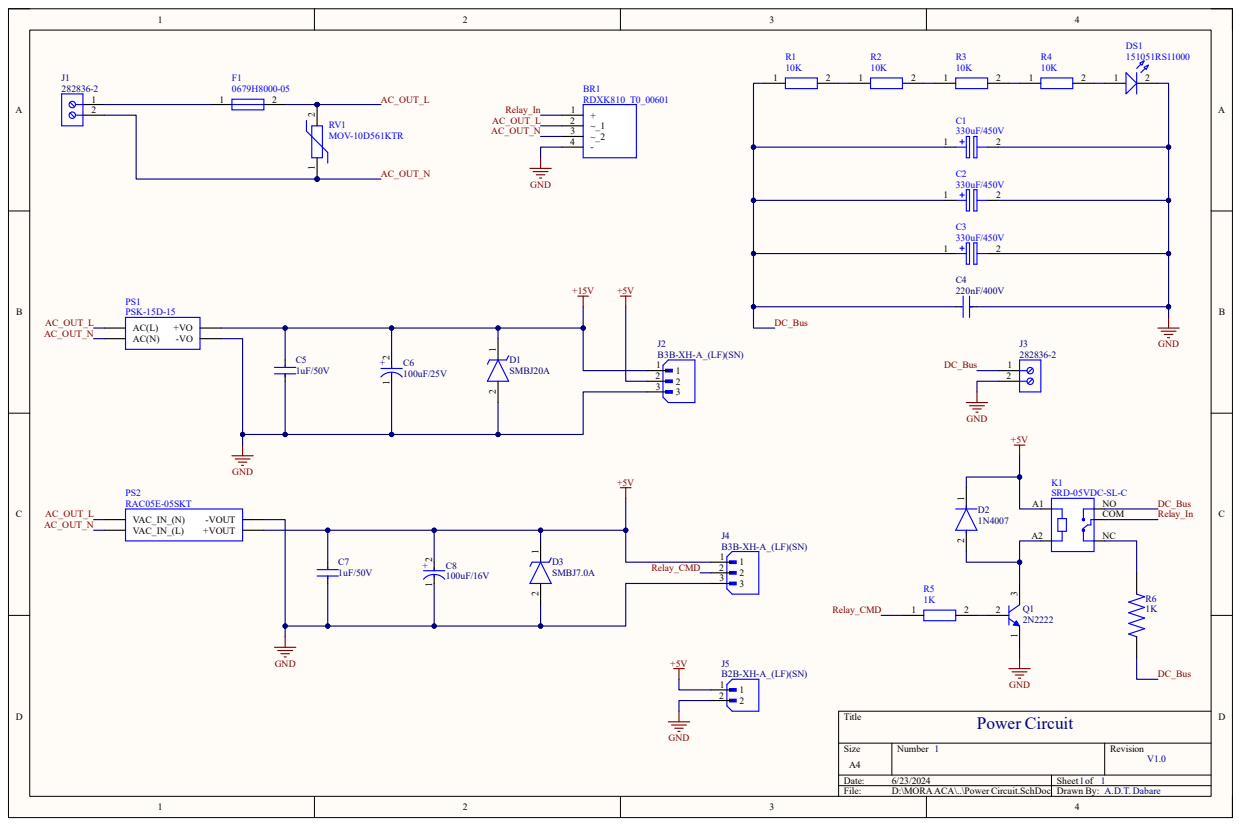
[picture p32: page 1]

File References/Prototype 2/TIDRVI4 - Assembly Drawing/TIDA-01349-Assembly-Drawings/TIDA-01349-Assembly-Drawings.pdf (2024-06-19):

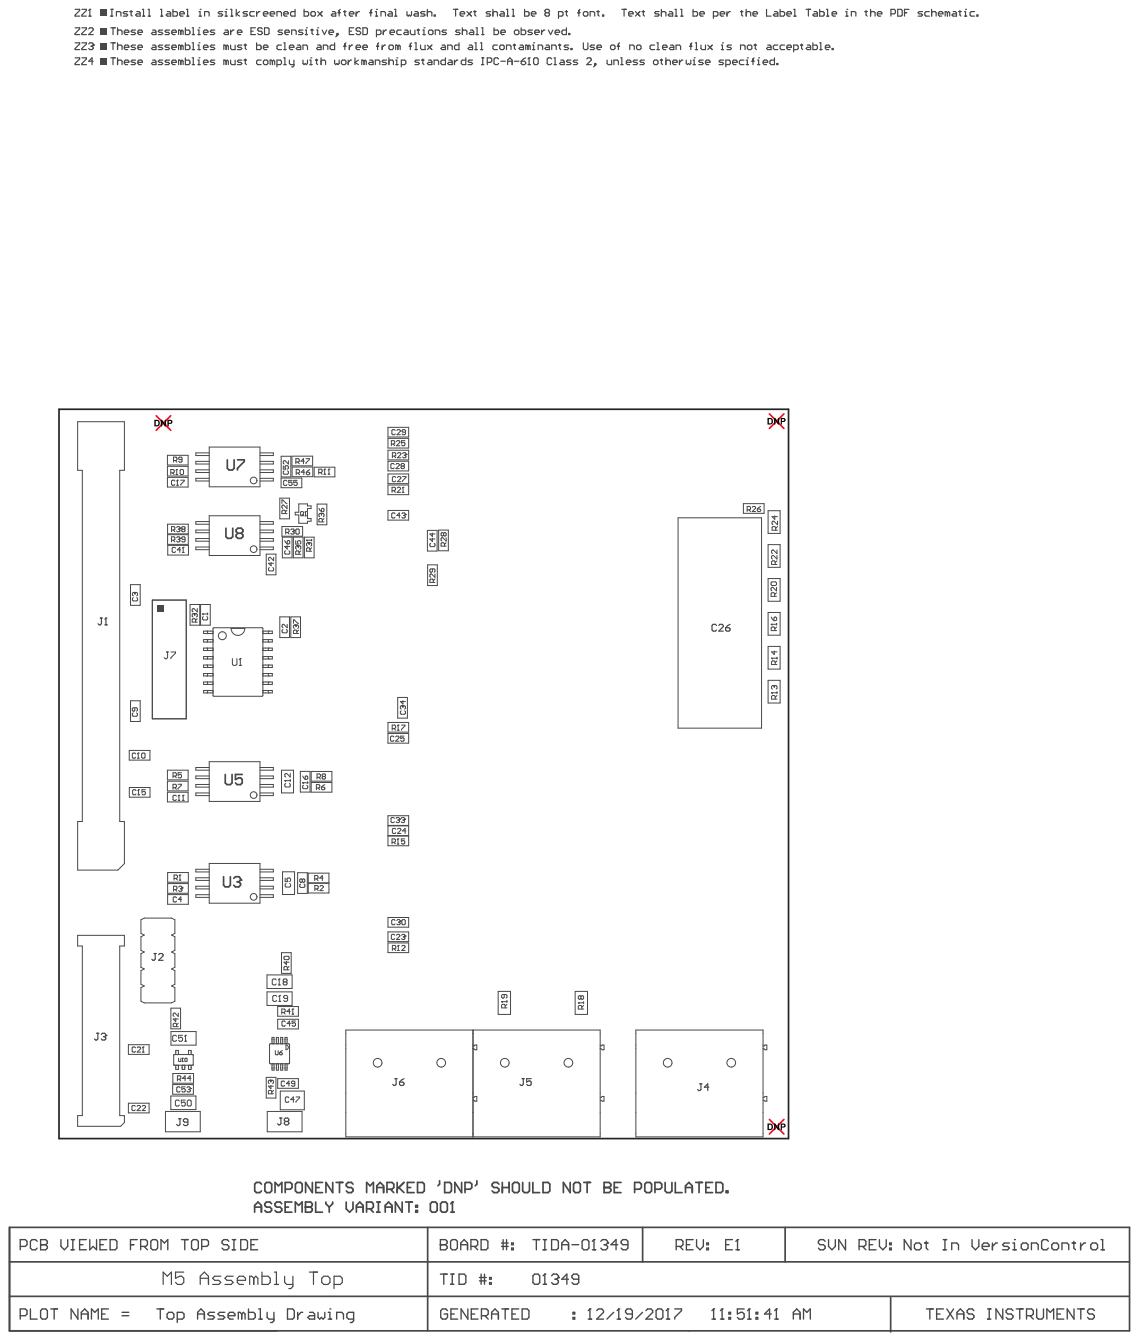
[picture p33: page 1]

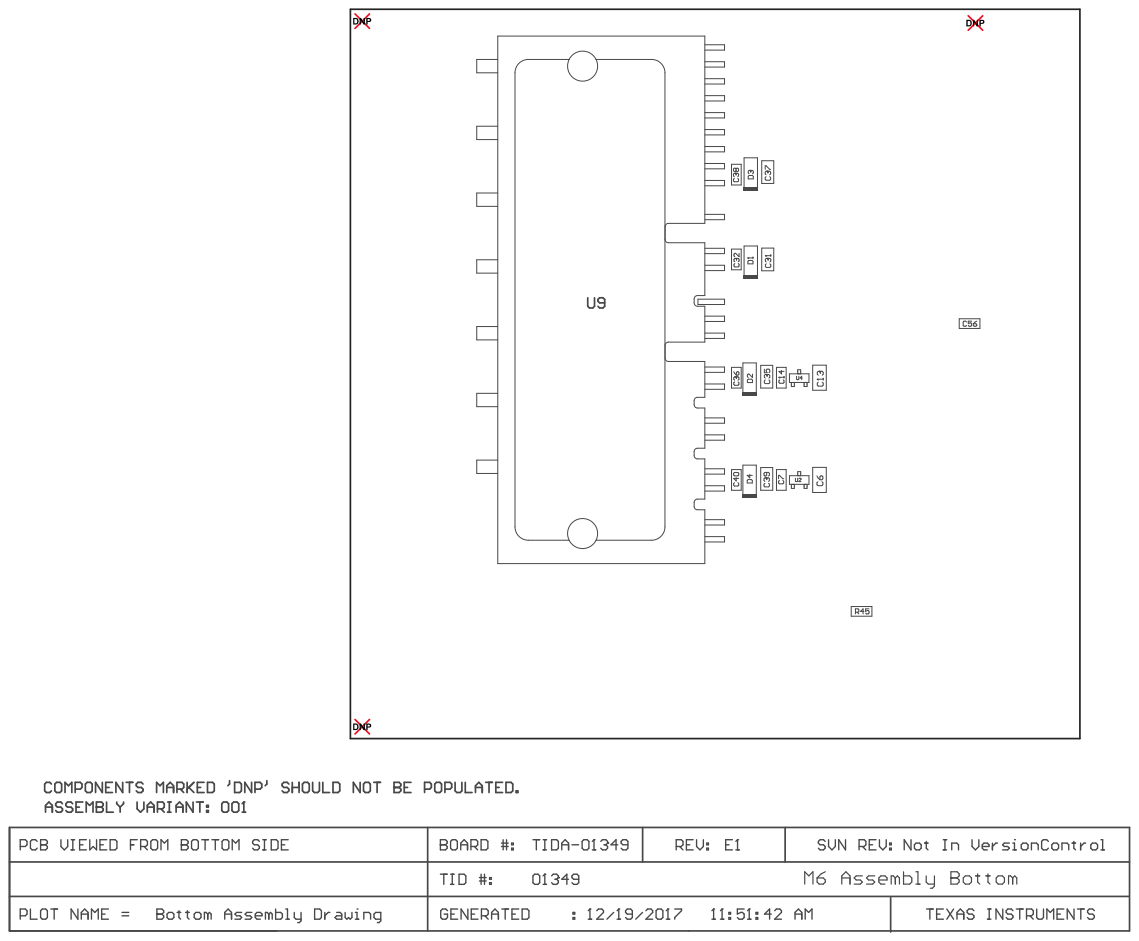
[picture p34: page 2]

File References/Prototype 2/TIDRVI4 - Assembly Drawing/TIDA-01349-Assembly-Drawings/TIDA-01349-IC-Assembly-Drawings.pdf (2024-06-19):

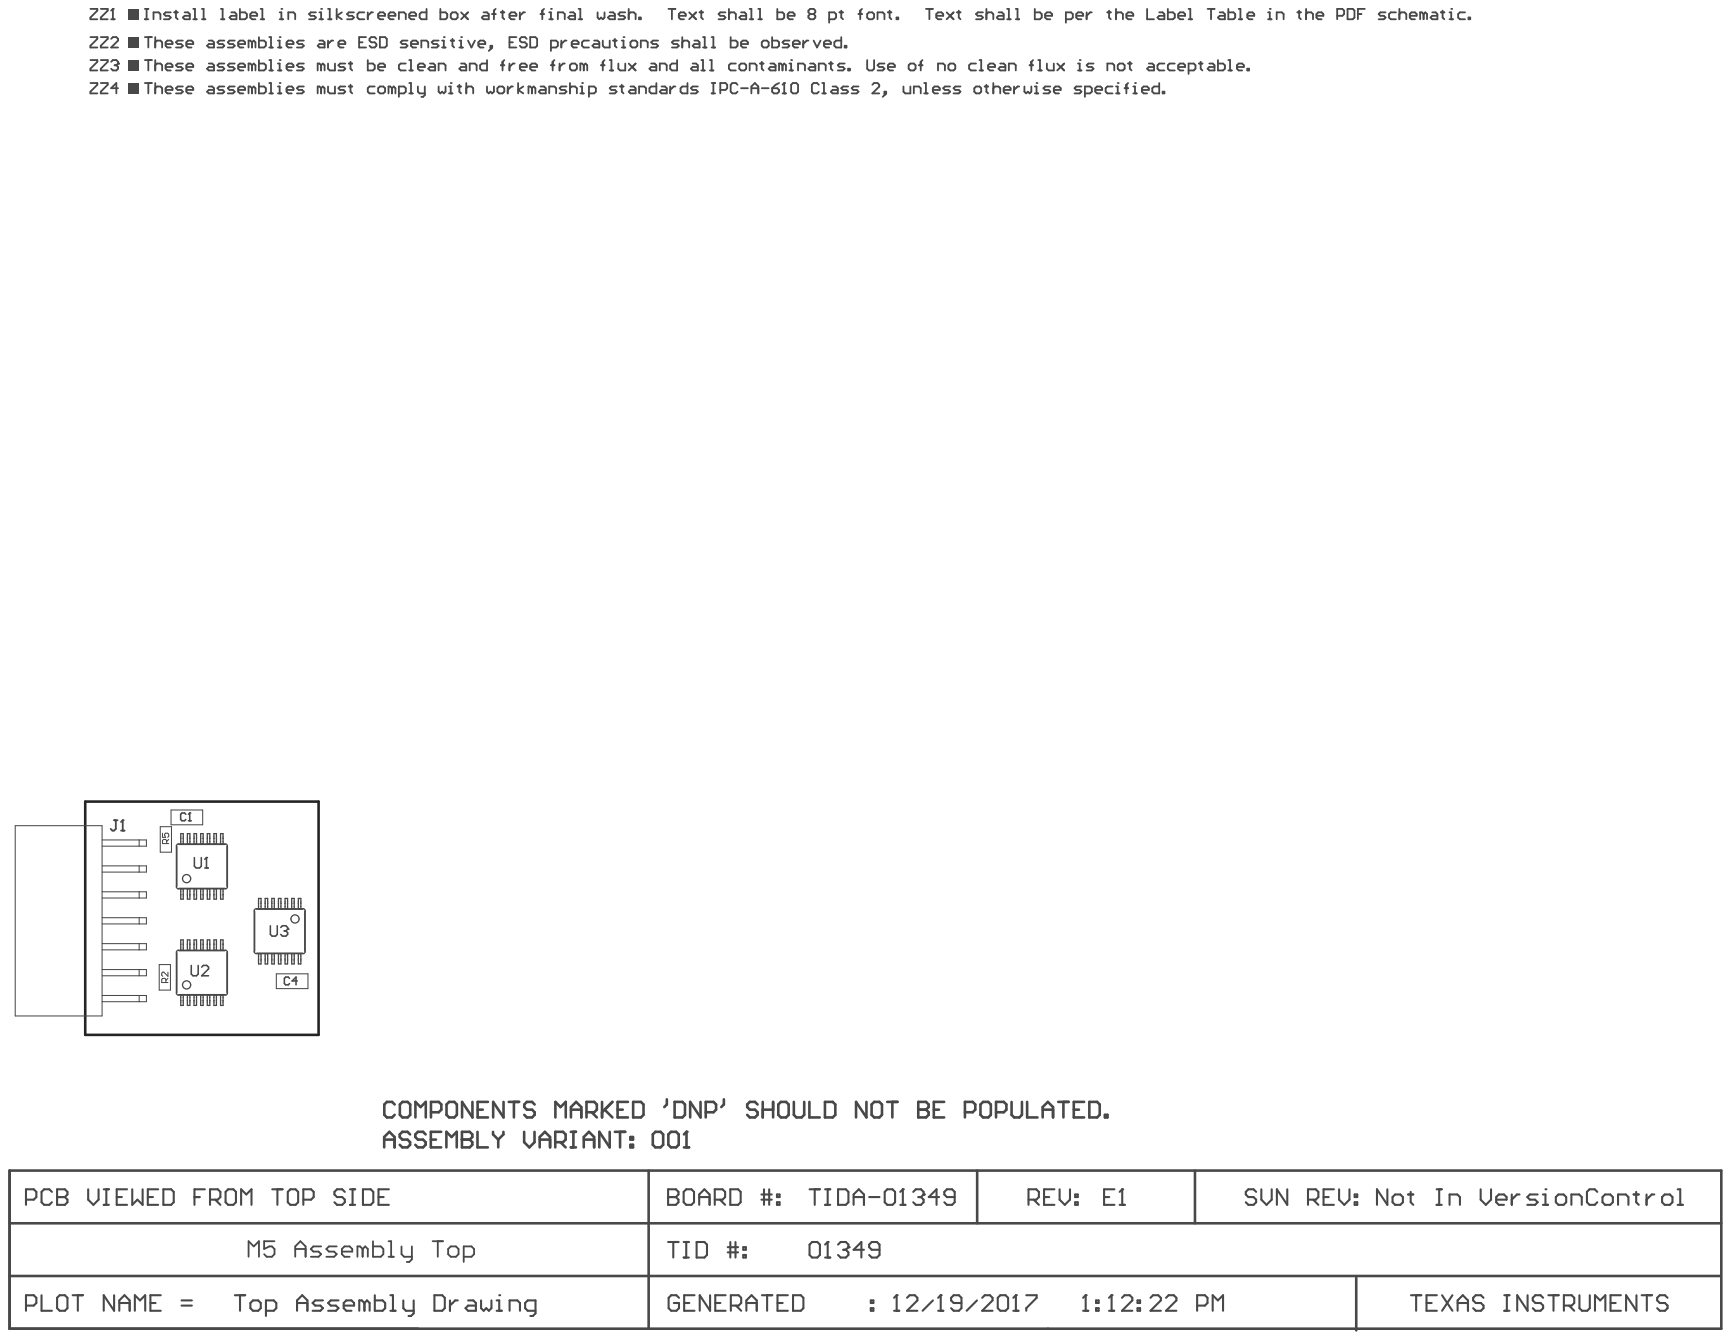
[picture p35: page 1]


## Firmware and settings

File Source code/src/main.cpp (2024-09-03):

/* MIT License

Original code by Matan Pazi
Copyright (c) 2023 Matan Pazi

Modifications by Lahiru Cooray
Copyright (c) 2024 LahiruCooray

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
Modifications
The following modifications have been made to the original code:

- Converted from Arduino to native AVR code.
- Removed functions related to single-phase AC motors.
- Added Reverse_3_Phase() function to enable reversing the rotation direction of the 3-phase AC motor.
- Adapted display libraries from Arduino to AVR.
*/

#define F_CPU 16000000UL
#include <stdint.h>
#include <avr/interrupt.h>
#include <avr/io.h>
#include <util/delay.h>
#include "TM1637Display_avr.h"

#define CLK1 PORTB4
#define DIO1 PORTB5
#define CLK2 PORTB6
#define DIO2 PORTB7
#define CURR_INPUT A0
#define POT_INPUT A2
//
#define THREE_PH 0
#define PWM_RUNNING 2
#define PWM_NOT_RUNNING 1
#define PWM_NOT_SET 0
#define DEADTIME_ADD  5
#define DEADTIME_SUB  2
#define SHORT_CLICK     10
#define LONG_CLICK      500
#define POT_SWITCH_SAMPLES  2
#define BOOT_CAP_CHARGE_TIME   160         
#define RELAY_CHARGE_WAIT      2000000     
#define DISPLAY_BLINK   100
#define MIN_PWM_VAL   6                   
#define BUTTON_IS_PRESSED      (!((PINC >> PINC4) & 1))      
#define POT_SWITCH_IS_ON       (!((PINC >> PINC3) & 1))      


const uint8_t THREE_PHASE[] = {
    SEG_A | SEG_B | SEG_C | SEG_D | SEG_G,            
    SEG_A | SEG_B | SEG_E | SEG_F | SEG_G,            
    SEG_B | SEG_C | SEG_E | SEG_F | SEG_G,            
    0,                                                
    };
const uint8_t SPACE[] = {
    0,                                                
    }; 

const float Sine[] = {125.0,179.0,223.0,246.0,246.0,223.0,179.0,125.0,71.0,27.0,6.0,6.0,27.0,71.0,125.0};
const uint8_t Sine_Len = 15;              
const uint8_t Min_Freq = 20;              
const uint8_t Max_Freq = 120;             
const uint16_t Base_Freq = 1041;          
const float Min_Amp = 0.1;                
const float Max_Amp = 1.0;                
const float V_f = 1.66667;                
const float VBus = 230.0;                 
bool  Phase_Config = 0;                   
bool  Config_Editable = 0;               
int16_t Sine_Used[] = {125,179,223,246,246,223,179,125,71,27,6,6,27,71,125};
uint8_t  Click_Type = 0;                  
uint8_t  PWM_Running = PWM_NOT_SET;       
uint32_t Timer = 0;                      
uint32_t Click_Timer = 0;                 
uint32_t Pot_Switch_Off_Timer = 0;        
uint32_t Pot_Switch_On_Timer = 0;         
uint32_t Display_Timer = 0;               
uint32_t Timer_Temp = 0;                  
uint32_t Timer_Temp1 = 0;                 
uint32_t Init_PWM_Counter = 0;            
uint16_t Curr_Value = 0;                  
uint8_t Sine_Index = 0;                   
uint8_t Sine_Index_120 = Sine_Len / 3;
uint8_t Sine_Index_240 = (Sine_Len * 2) / 3;       
uint8_t OVF_Counter = 0;                                                   
uint8_t OVF_Counter_Compare = 0;          


TM1637Display Display1(CLK1, DIO1);
TM1637Display Display2(CLK2, DIO2);


void Button_Click();
void Display(uint8_t PWM_Running, bool Blink, uint8_t Desired_Freq);
void Pot_Switch_State_Check();
void Reverse_3_Phase();
void Wait_A_Bit(uint32_t Executions_To_Wait);
void Pwm_Disable();
void Pwm_Config();
void ADC_init();
uint16_t analogRead(uint8_t channel) ;



void setup()
{
  cli();                                      
  CLKPR = (1 << CLKPCE);                      
  CLKPR = (1 << CLKPS0);                      
  sei();
  Display1.setBrightness(0x02);
  Display2.setBrightness(0x02);
  Display1.clear();
  Display2.clear();
  PORTC = (1 << PORTC3) | (1 << PORTC4);         
  DDRD = (1 << DDD6) | (1 << DDD5) | (1 << DDD3); 
  DDRB = (1 << DDB3) | (1 << DDB2) | (1 << DDB1) | (1 << DDB0); 
                                                                
  Wait_A_Bit(RELAY_CHARGE_WAIT);              
                                              
  PORTB = (1 << PORTB0);                      
}


void loop()
{   
   uint8_t Desired_Freq;                                 
   uint8_t OVF_Counter_Compare_Temp;                     
   float Amp; 
   ADC_init();
   Curr_Value = analogRead(0) << 3;                 
   Desired_Freq = ((uint8_t)(analogRead(2) >> 3));   
   if (Desired_Freq < Min_Freq) Desired_Freq = Min_Freq;
   else if (Desired_Freq > Max_Freq) Desired_Freq = Max_Freq;
   OVF_Counter_Compare_Temp = (uint8_t)(Base_Freq / Desired_Freq);                     
   {
      OVF_Counter_Compare = OVF_Counter_Compare_Temp;       
                                                                                                  
   }
   Amp = ((float)(Desired_Freq) * V_f) / VBus;                      
   if (Amp < Min_Amp) Amp = Min_Amp;      
   else if (Amp > Max_Amp) Amp = Max_Amp;                 
   {
      for (int i = 0; i < Sine_Len; i++)
      {
         Sine_Used[i] = (int16_t)(Amp * Sine[i]); 
      }
   }

   Pot_Switch_State_Check();
   if (BUTTON_IS_PRESSED) Button_Click();
   if (PWM_Running != PWM_NOT_SET) Display(PWM_Running, Config_Editable, Desired_Freq);
   Timer++;    
}


int main()
{
    setup();
    while (1)
    {
        loop();
    }
    return 0;
}


void Button_Click()
{
  if (BUTTON_IS_PRESSED)
  {
    if (Timer - Timer_Temp1  > 1) Click_Timer = 0;    
    else Click_Timer++;
    Timer_Temp1 = Timer;
    if (Click_Timer > SHORT_CLICK)
    {
      Reverse_3_Phase();    
    }
    Click_Timer = 0;
  } 

  else Click_Timer = 0;
}


void Display(uint8_t PWM_Running, bool Blink, uint8_t Desired_Freq)
{
  if (PWM_Running == PWM_RUNNING)
  {
    if (Desired_Freq > 99) Display1.showNumberDec(Desired_Freq, false, 3, 1);
    else 
    {
      Display1.setSegments(SPACE, 1, 1);
      Display1.showNumberDec(Desired_Freq, false, 2, 2);         
    }
    if (Curr_Value > 999) Display2.showNumberDec(Curr_Value, false, 4, 0);
    else 
    {
      Display2.setSegments(SPACE, 1, 0);
      Display2.showNumberDec(Curr_Value, false, 3, 1);         
    }
  }
  else
  {
    Display_Timer++;
    if (Blink && (Display_Timer == DISPLAY_BLINK))
    {
      Display1.clear();
      Display2.clear();
    }
    else if (Display_Timer > (2*DISPLAY_BLINK))
    { 
      Display1.setSegments(THREE_PHASE); 
      Display_Timer = 0;   
    }
  }
}


void Wait_A_Bit(uint32_t Executions_To_Wait)
{
  volatile uint32_t Timer_Temp2 = 0;
  while (Timer_Temp2 < Executions_To_Wait)
  {
    Timer_Temp2++;
  }
}


void Pwm_Disable()
{
   PWM_Running = PWM_NOT_RUNNING;
   cli();
   Init_PWM_Counter = 0;
   TCCR0A = 0;
   TCCR0B = 0;
   TCCR1A = 0;
   TCCR1B = 0;
   TCCR2A = 0;
   TCCR2B = 0;
   sei();    
}

void Pwm_Config()
{
   if (Phase_Config == THREE_PH)  
   {
       cli();                      
       PWM_Running = PWM_RUNNING;
       GTCCR = (1<<TSM)|(1<<PSRASY)|(1<<PSRSYNC); 
       TCCR0A = (1 << COM0A1) | (1 << COM0B1) | (1 << COM0B0) | (1 << WGM00); 
       TCCR0B = (1 << CS00);      
       TIMSK0 = (1 << TOIE0);     
       OCR0A = 0;     
       OCR0B = 127;   
       TCCR1A = (1 << COM1A1) | (1 << COM1B1) | (1 << COM1B0) | (1 << WGM10); 
       TCCR1B = (1 << CS10);      
       OCR1A = 0;     
       OCR1B = 127;   
       TCCR2A = (1 << COM2A1) | (1 << COM2B1) | (1 << COM2B0) | (1 << WGM20); 
       TCCR2B = (1 << CS20);       
       OCR2A = 0;    
       OCR2B = 127;  
       TCNT0 = 0;     
       TCNT1H = 0;    
       TCNT1L = 0;    
       TCNT2 = 0;         
       GTCCR = 0;     
       Init_PWM_Counter = 0;
       Wait_A_Bit(BOOT_CAP_CHARGE_TIME);
       sei();      
   }

}


void Pot_Switch_State_Check()    
{
   if (POT_SWITCH_IS_ON)
   {      
      if (PWM_Running != PWM_RUNNING)   
      {
        if (Timer - Timer_Temp  > 1) Pot_Switch_On_Timer = 0;   
        else  Pot_Switch_On_Timer++;      
        Timer_Temp = Timer;
        Pot_Switch_Off_Timer = 0;
        if (Pot_Switch_On_Timer > POT_SWITCH_SAMPLES)  
        {
          Pwm_Config();      
          Pot_Switch_On_Timer = 0;
          Pot_Switch_Off_Timer = 0;      
          Display1.clear();
          Display2.clear();
        }         
      }
   }
   else          
   {
      if (PWM_Running != PWM_NOT_RUNNING)     
      {
        if (Timer - Timer_Temp  > 1) Pot_Switch_Off_Timer = 0;  
        else  Pot_Switch_Off_Timer++;      
        Timer_Temp = Timer;
        Pot_Switch_On_Timer = 0;
        if (Pot_Switch_Off_Timer > POT_SWITCH_SAMPLES)  
        {
          Pwm_Disable();
          Pot_Switch_On_Timer = 0;
          Pot_Switch_Off_Timer = 0;
          Display1.clear();
          Display2.clear();
        } 
      }
   }    
}


ISR (TIMER0_OVF_vect)
{   
   OVF_Counter++;   
   if (OVF_Counter >= OVF_Counter_Compare)
   {
      if (Sine_Index == Sine_Len) Sine_Index = 0;
      if (Sine_Index_120 == Sine_Len) Sine_Index_120 = 0;
      if (Sine_Index_240 == Sine_Len) Sine_Index_240 = 0;    
      //  
      if ((Sine_Used[Sine_Index] - DEADTIME_SUB) < MIN_PWM_VAL)        
      {
         OCR0A = 0;
      }
      else
      {
         OCR0A = uint8_t(Sine_Used[Sine_Index] - DEADTIME_SUB);
      }
      OCR0B = OCR0A + DEADTIME_ADD;                            

      if ((Sine_Used[Sine_Index_120] - DEADTIME_SUB) < MIN_PWM_VAL)    
      {
         OCR1A = 0;
      }
      else
      {
         OCR1A = uint8_t(Sine_Used[Sine_Index_120] - DEADTIME_SUB);    
      }
      OCR1B = OCR1A + DEADTIME_ADD;

      if ((Sine_Used[Sine_Index_240] - DEADTIME_SUB) < MIN_PWM_VAL)
      {
          OCR2A = 0;
      }            
      else
      {
          OCR2A = uint8_t(Sine_Used[Sine_Index_240] - DEADTIME_SUB);
      }
      OCR2B = OCR2A + DEADTIME_ADD;

      OVF_Counter = 0;
      Sine_Index++;
      Sine_Index_120++;
      Sine_Index_240++;
   }
}


void Reverse_3_Phase()
{ 
    if (Phase_Config == 0)
    {
        Pwm_Disable();
        uint8_t tempIndex = Sine_Index_120;
        Sine_Index_120 = Sine_Index_240;
        Sine_Index_240 = tempIndex;
        PORTB &= ~((1 << PORTB1) | (1 << PORTB2) | (1 << PORTB3));
        PORTD &= ~((1 << PORTD3) | (1 << PORTD5) | (1 << PORTD6));
    }
}


void ADC_init()
{
    ADMUX |= (1 << REFS0);
    ADMUX &= ~(1 << REFS1);
    ADCSRA |= (1 << ADPS2) | (1 << ADPS1) | (1 << ADPS0);
    ADCSRA |= (1 << ADEN);
}


uint16_t analogRead(uint8_t channel)
{
    channel &= 0b00000111;
    ADMUX = (ADMUX & 0xF8) | channel;
    ADCSRA |= (1 << ADSC);
    while (ADCSRA & (1 << ADSC));
    return ADC;
}

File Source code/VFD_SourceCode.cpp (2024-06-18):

/* MIT License

Original code by Matan Pazi
Copyright (c) 2023 Matan Pazi

Modifications by Lahiru Cooray
Copyright (c) 2024 Lahiru Cooray

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
THE SOFTWARE IS PROVIDED "AS IS", WITHOUT WARRANTY OF ANY KIND, EXPRESS OR
IMPLIED, INCLUDING BUT NOT LIMITED TO THE WARRANTIES OF MERCHANTABILITY,
FITNESS FOR A PARTICULAR PURPOSE AND NONINFRINGEMENT. IN NO EVENT SHALL THE
AUTHORS OR COPYRIGHT HOLDERS BE LIABLE FOR ANY CLAIM, DAMAGES OR OTHER
LIABILITY, WHETHER IN AN ACTION OF CONTRACT, TORT OR OTHERWISE, ARISING FROM,
OUT OF OR IN CONNECTION WITH THE SOFTWARE OR THE USE OR OTHER DEALINGS IN
THE SOFTWARE. */

#define _DISABLE_ARDUINO_TIMER0_INTERRUPT_HANDLER_  // These 2 lines were added to be able to compile. Also changed wiring.c file. 
#include <wiring.c>                                 // Reference: https://stackoverflow.com/questions/46573550/atmel-arduino-isrtimer0-ovf-vect-wont-compile-first-defined-in-vector/48779546
#include <stdint.h>
#include <avr/interrupt.h>
#include <avr/io.h>
#include <EEPROM.h>
#include <TM1637Display.h>

// Module connection pins (Digital Pins)
#define CLK1 12
#define DIO1 2
#define CLK2 7
#define DIO2 4
#define CURR_INPUT A0
#define POT_INPUT A2
//
#define THREE_PH 0
#define PWM_RUNNING 2
#define PWM_NOT_RUNNING 1
#define PWM_NOT_SET 0
#define DEADTIME_ADD  5
#define DEADTIME_SUB  2
//millis(), delay() don't work as expected due to use of timers in PWM.
#define SHORT_CLICK     10
#define LONG_CLICK      500
#define POT_SWITCH_SAMPLES  2
#define BOOT_CAP_CHARGE_TIME   160         // Need at least 10 [ms] to charge the boot caps. Chosen through trial and error.
#define RELAY_CHARGE_WAIT      2000000     // Approx. 8 seconds
#define DISPLAY_BLINK   100
#define MIN_PWM_VAL   6                   // Due to isolator response time. Found through trial and error
#define BUTTON_IS_PRESSED      (!((PINC >> PINC4) & 1))      // Pin 4 of port C (Button) is pressed. when button is pushed, PINC4 is pulled LOW.
#define POT_SWITCH_IS_ON       (!((PINC >> PINC3) & 1))      // Pin 3 of port C (Potentiometer switch) is on. when switch is on, PINC3 is pulled LOW.


const uint8_t THREE_PHASE[] = {
    SEG_A | SEG_B | SEG_C | SEG_D | SEG_G,            // 3
    SEG_A | SEG_B | SEG_E | SEG_F | SEG_G,            // P
    SEG_B | SEG_C | SEG_E | SEG_F | SEG_G,            // H
    0,                                                // space
    };
const uint8_t SPACE[] = {
    0,                                                // space
    }; 

const float Sine[] = {125.0,179.0,223.0,246.0,246.0,223.0,179.0,125.0,71.0,27.0,6.0,6.0,27.0,71.0,125.0};
const uint8_t Sine_Len = 15;              //Sine table length
const uint8_t Min_Freq = 20;              //Minimal demanded sine wave frequency
const uint8_t Max_Freq = 120;             //Maximal demanded sine wave frequency
const uint16_t Base_Freq = 1041;          //[Hz] Maximal frequency if the sine wave array index is incremented every OVF occurance 
const float Min_Amp = 0.1;                //Minimal allowed sine wave amplitude
const float Max_Amp = 1.0;                //Maximal allowed sine wave amplitude
const float V_f = 1.66667;                 //V/f value. 200Vac/120Hz for the motor we are testing the VFD on
const float VBus = 230.0;                 //AC voltage [VAC]
bool  Phase_Config = 0;                   //0: 3 phase
bool  Config_Editable = 0;               
int16_t Sine_Used[] = {125,179,223,246,246,223,179,125,71,27,6,6,27,71,125};
uint8_t  Click_Type = 0;                  //1: Short, 2: Long
uint8_t  PWM_Running = PWM_NOT_SET;       //Indicates if the PWM is operating or not. 2 is running, 1 is not, initialized to 0 to indicate not yet set.
uint32_t Timer = 0;                       //Timer, increments every loop
uint32_t Click_Timer = 0;                 //Increments while button is clicked
uint32_t Pot_Switch_Off_Timer = 0;        //Increments while potentiometer switch is OFF
uint32_t Pot_Switch_On_Timer = 0;         //Increments while potentiometer switch is ON
uint32_t Display_Timer = 0;               //Used for delay of the blinking display (When configurable)
uint32_t Timer_Temp = 0;                  //Used to make sure of consecutive executions
uint32_t Timer_Temp1 = 0;                 //Used to make sure of consecutive executions
uint32_t Init_PWM_Counter = 0;            //Used for charging the bootstrap capacitors, source below
uint16_t Curr_Value = 0;                  //Current value measured in [mA]
uint8_t Sine_Index = 0;                   //3 sine wave indices are used to allow for phase shifted sine waves.
uint8_t Sine_Index_120 = Sine_Len / 3;
uint8_t Sine_Index_240 = (Sine_Len * 2) / 3;       //Sine_Len must be lower than 128, otherwise, change eq. 
uint8_t OVF_Counter = 0;                  //Increments every Timer0 overflow                                          
uint8_t OVF_Counter_Compare = 0;          //Compare OVF_Counter to this value (Base freq / desired freq).



TM1637Display Display1(CLK1, DIO1);
TM1637Display Display2(CLK2, DIO2);

void setup()
{
  cli();                                      //Disable interrupts
  CLKPR = (1 << CLKPCE);                      //Enable change of the clock prescaler
  CLKPR = (1 << CLKPS0);                      //Set system clock prescaler to 2. Beforehand DT had to be increased to a large value due to IPM, and at low amplitudes distorted sine wave. When reducing the prescaler, this allows for the DT value to be small.
  sei();
  Display1.setBrightness(0x02);
  Display2.setBrightness(0x02);
  Display1.clear();
  Display2.clear();
  PORTC = (1 << PORTC3) | (1 << PORTC4);      //Activates internal pull up for PC3 (ADC3) and PC4 (ADC4). Default pin state is input. Potentiometer switch and button respectively   
  DDRD = (1 << DDD6) | (1 << DDD5) | (1 << DDD3); //Sets the OC0A, OC0B and OC2B pins to outputs (Default is LOW)
  DDRB = (1 << DDB3) | (1 << DDB2) | (1 << DDB1) | (1 << DDB0); //Sets the OC2A, OC1B and OC1A pins to outputs (Default is LOW)
                                                                //And sets PB0 pin to output (Default is LOW). Commands the relay
  Wait_A_Bit(RELAY_CHARGE_WAIT);              //Using this function since delay() doesn't seem to work correctly when ISR is activated. Not needed to delay if interrupts are enabled.
                                              //Waiting this delay to let the capacitors charge up. Requires ~3 seconds.
  PORTB = (1 << PORTB0);                      //Set output pin to the relay high, to bypass the high power resistor after the caps were sufficiently charged
}
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

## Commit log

2024-05-03 Add files via upload
    2nd attempt
    [Assembly VFD.SLDASM, Main.SLDPRT, Top cover VFD.SLDPRT]
2024-05-03 2nd attempt with 2mm outer wall thickness
    [Assembly VFD.SLDASM, Main.SLDPRT, Top cover VFD.SLDPRT]
2024-06-18 This is the finalized moldable enclosure design.
    I have finalized the enclosure design for the VFD project, which needs to be moldable. Therefore, I created mold designs for each part.
    [Assembly VFD.SLDASM, Body1.SLDPRT, Body2.SLDPRT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]
